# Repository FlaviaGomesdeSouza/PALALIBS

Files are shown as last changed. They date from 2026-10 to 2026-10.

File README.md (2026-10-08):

# Porta-amostras de 30 mm para pastilhas prensadas de 13 mm (LA-ICP-MS / LIBS)

É um cilindro com a seção de 30 mm que o porta-amostras do equipamento já aceita, com cavidades para
pastilhas de 13 mm. Segue a mesma ideia dos porta-amostras de seções polidas de MEV: a pastilha fica
**presa mecanicamente**, mesmo com o porta-amostras inclinado, e a **altura de cada pastilha é
ajustável**, de modo que todas as faces de análise ficam no mesmo plano. Não usa resina e não precisa
de polimento.

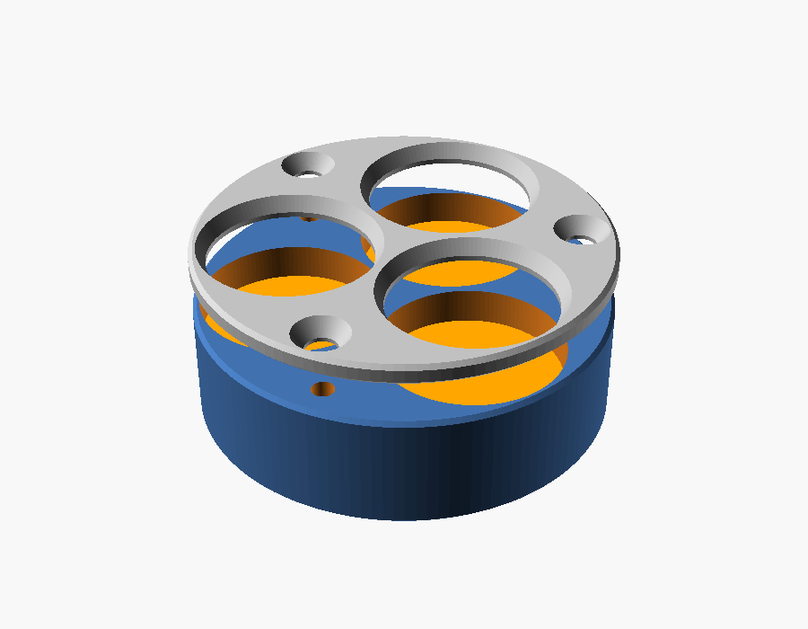
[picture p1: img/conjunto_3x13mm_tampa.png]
Conjunto para 3 pastilhas com tampa de fixação


## Ajuste de altura (todas as versões)

Cada cavidade tem um **pistão** (disco solto de 12,9 mm) sob a pastilha. Um **parafuso M3 sem cabeça**,
que entra por baixo, empurra o pistão para cima. Cada pastilha é regulada de forma independente, o que
compensa a diferença de espessura entre elas. O mesmo parafuso serve para extrair a pastilha.

## Fixação: duas opções

### A) Tampa de fixação (`fixacao = "tampa"`): recomendada; serve para 1, 2 ou 3 pastilhas

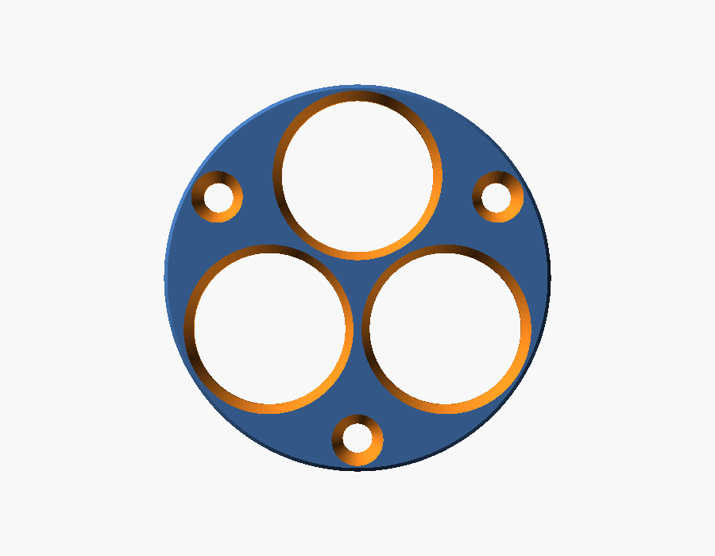
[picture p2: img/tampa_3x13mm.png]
Tampa


- A tampa é presa com parafusos M2 de cabeça chata escareada. Ela tem janelas de 11,8 mm, e a borda de
  cada janela cobre **0,6 mm** da borda da pastilha.
- Ao apertar o parafuso de baixo, a pastilha sobe até encostar na borda da janela. Isso **prende e
  nivela ao mesmo tempo**: todas as faces ficam encostadas no mesmo plano (a face inferior da tampa),
  seja qual for a espessura de cada pastilha.
- A face de análise fica 1,5 mm abaixo do topo. A janela tem chanfro, o que deixa espaço para o feixe e
  para o plasma com o porta-amostras inclinado.
- Área útil: círculo de ~11,8 mm em cada pastilha.

**Montagem:**
1. Coloque o pistão e a pastilha (face para cima) em cada cavidade.
2. Parafuse a tampa.
3. Por baixo, aperte cada parafuso M3 até a pastilha encostar na tampa. Encostou e travou, pare: o
   aperto deve ser leve, para não trincar a pastilha. Se quiser amortecer, coloque um disco fino de
   silicone ou de papel entre o pistão e a pastilha.

### B) Parafuso lateral com calço (`fixacao = "lateral"`): só para 1 ou 2 pastilhas

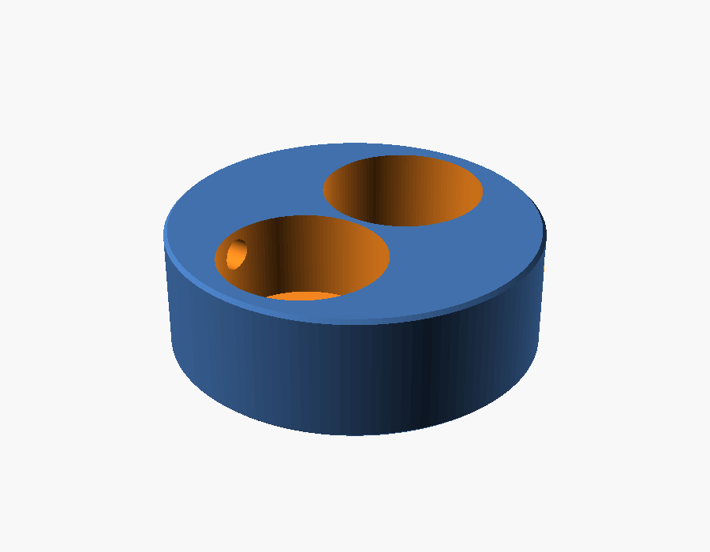
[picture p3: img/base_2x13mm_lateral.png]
Base com parafuso lateral


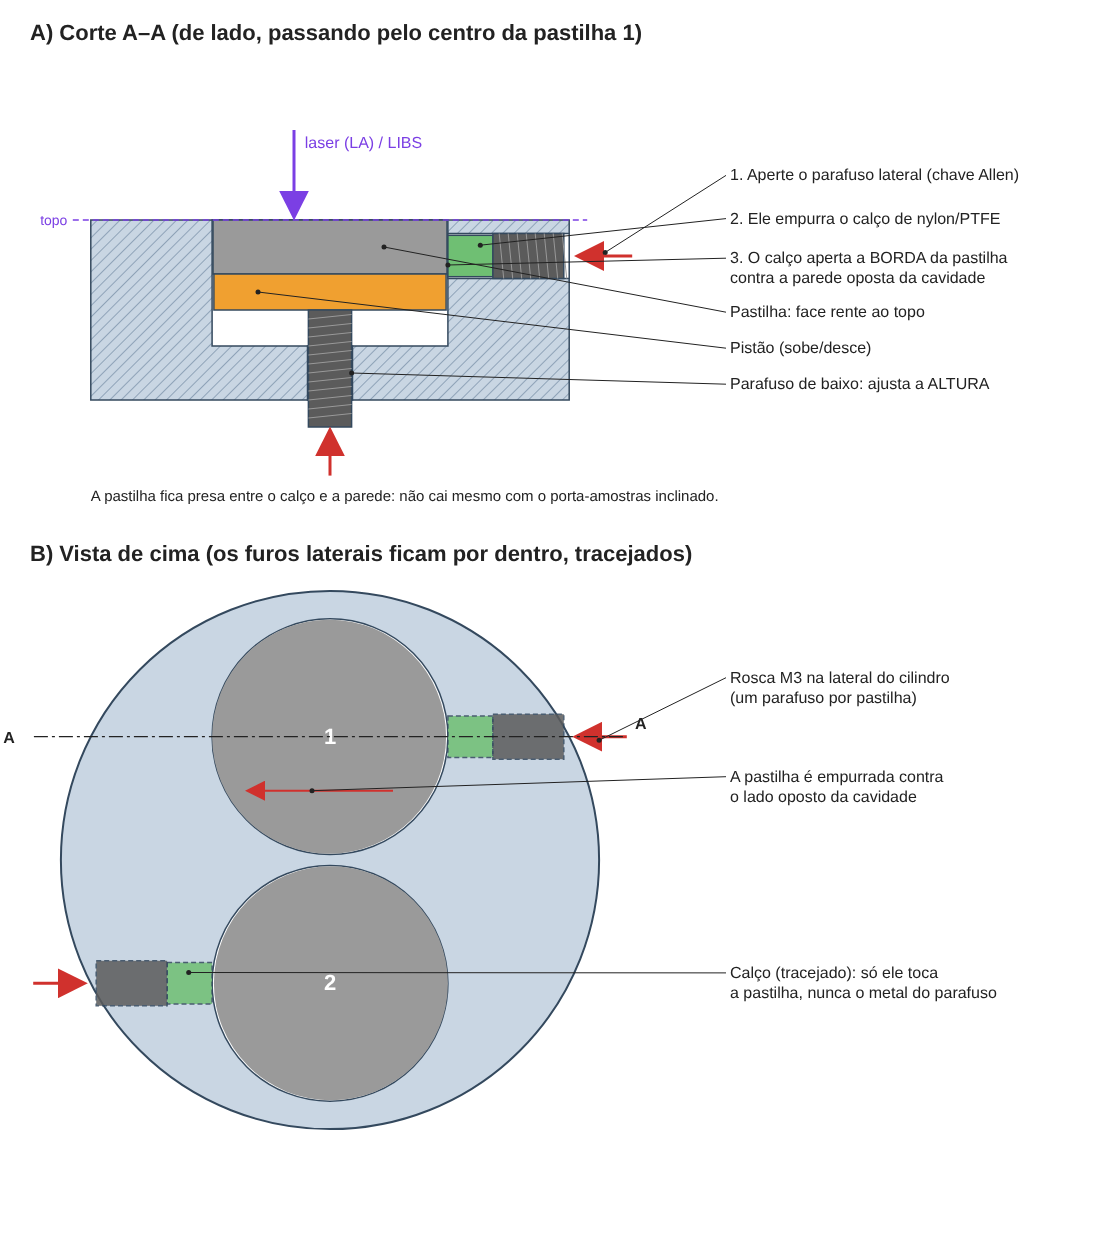
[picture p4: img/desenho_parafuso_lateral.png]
Como funciona o parafuso lateral: corte e vista de cima


- Um parafuso M3 sem cabeça entra pela lateral do cilindro, como nos porta-amostras de MEV, e empurra um
  **calço de nylon ou PTFE** (Ø 2,3 × 2,5 mm) contra a borda da pastilha.
- A face fica **rente ao topo**, e nenhuma parte da pastilha fica coberta.
- O furo lateral está a 2 mm abaixo do topo, então a pastilha precisa ter **pelo menos ~2 mm de
  espessura** para o calço alcançá-la. Para pastilhas mais finas, use a versão com tampa.
- **Com 3 pastilhas não é possível:** três círculos de 13 mm ocupam quase todo o círculo de 30 mm e a
  parede da borda fica com ~0,5 mm, sem espaço para rosca.

**Montagem e nivelamento:**
1. Apoie uma lâmina de vidro limpa na bancada e coloque as pastilhas sobre ela com a face de análise
   para baixo.
2. Encaixe a base por cima, de cabeça para baixo.
3. Coloque os pistões e aperte os parafusos de baixo só até encostar.
4. Aperte os parafusos laterais.
5. Vire o conjunto. As faces ficam rentes ao topo e no mesmo plano.

## Arquivos

| Arquivo | Peça |
|---|---|
| `porta_amostras_30mm.scad` | Modelo paramétrico (OpenSCAD). Abra em *Window → Customizer* para mudar as medidas. |
| `stl/base_3x13mm_tampa.stl` + `stl/tampa_3x13mm.stl` | 3 pastilhas, fixação por tampa (3 parafusos M2) |
| `stl/base_2x13mm_tampa.stl` + `stl/tampa_2x13mm.stl` | 2 pastilhas, fixação por tampa (2 parafusos M2) |
| `stl/base_2x13mm_lateral.stl` | 2 pastilhas, parafuso lateral |
| `stl/base_1x13mm_lateral.stl` | 1 pastilha, parafuso lateral |
| `stl/pistao_13mm.stl` | Pistão (um por cavidade) |
| `stl/calco_lateral.stl` | Calço do parafuso lateral; de preferência, corte de um tarugo de nylon ou PTFE |

### Parafusos (por suporte)

| Versão | Fundo (altura) | Fixação |
|---|---|---|
| Tampa, 3 pastilhas | 3 × M3 sem cabeça (DIN 913), 8–10 mm | 3 × M2 × 8 cabeça chata (DIN 965) |
| Tampa, 2 pastilhas | 2 × M3 sem cabeça, 8–10 mm | 2 × M2 × 8 cabeça chata |
| Lateral, 2 pastilhas | 2 × M3 sem cabeça, 8–10 mm | 2 × M3 sem cabeça, 6 mm, + 2 calços |

### Medidas padrão

- Ø externo 29,9 mm e altura total de 10 mm (com tampa: base de 8,5 mm + tampa de 1,5 mm).
- Cavidades de Ø 13,1 mm.
- Espessura máxima de pastilha: 3,5 mm na versão com tampa e 5 mm na versão lateral.

**Antes de fabricar, confira** a altura máxima que o porta-amostras do equipamento aceita e altere
`altura`, se precisar.

## Versão para impressão FDM (Bambu Lab X1 Carbon)

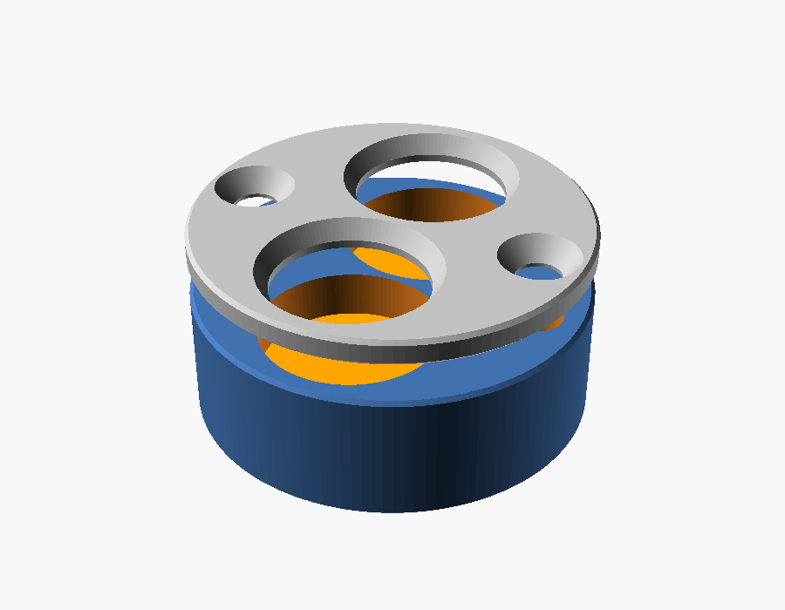
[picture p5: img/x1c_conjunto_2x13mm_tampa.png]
Versão X1C, 2 pastilhas com tampa


O arquivo `x1c_fdm.scad` usa o modelo principal com medidas próprias para FDM. Os STL prontos estão em
`stl/x1c/`.

**Diferenças em relação à versão usinada:**
- Configurada para **policarbonato (PC)**. Em `x1c_fdm.scad`, `material = "PETG"` troca as folgas para
  PETG.
- Folgas que compensam a contração do PC (~0,5–0,7 %): cavidade com +0,4 mm, seção com −0,1 mm e furo
  de inserto de 4,1 mm.
- Chanfro de 0,6 mm na borda de baixo, para absorver o "pé de elefante" da primeira camada.
- Todas as roscas são M3 em **insertos de latão**.
- Tampa de 2 mm presa com M3 escareado.
- Altura total de **12 mm**. Confira se o porta-amostras aceita essa altura; se não aceitar, altere
  `altura` em `x1c_fdm.scad`.
- Só 1 ou 2 pastilhas. A versão para 3 não é imprimível em FDM.

| Arquivo (`stl/x1c/`) | Peça |
|---|---|
| `teste_encaixe.stl` | Anel de 3 mm para testar a pastilha e o porta-amostras. **Imprima este primeiro.** |
| `base_2x13mm_tampa.stl` + `tampa_2x13mm.stl` | 2 pastilhas, com tampa (pastilhas de até 4,4 mm) |
| `base_1x13mm_tampa.stl` + `tampa_1x13mm.stl` | 1 pastilha, com tampa |
| `base_2x13mm_lateral.stl` / `base_1x13mm_lateral.stl` | Parafuso lateral (pastilhas de 2 a 6,4 mm) |
| `pistao_13mm.stl` | Pistão (um por cavidade) |

### Material

| Peça | Filamento | Por quê |
|---|---|---|
| Base, pistões e tampa | **PC transparente / natural** (sem pigmento) | É rígido, aguenta calor, cede pouco sob o aperto da tampa e não tem pigmento metálico. |

**PLA-CF não é recomendado para a tampa:**
- O PLA amolece a ~55–60 °C e **deforma com o tempo sob carga constante**: a pastilha afrouxa.
- A fibra deixa o PLA mais rígido, mas também **mais quebradiço**, e a borda da janela é fina.
- É sempre preto (fibra de carbono e negro de fumo). Se o laser pegar a borda, aparecem C e CN no LIBS.

Se quiser mesmo um filamento com fibra, use **PETG-CF** ou **PA-CF**, que deformam bem menos. O PA
precisa estar muito seco: absorve umidade, que depois sai na purga de He/Ar.

### Configuração de impressão em PC (Bambu Studio)
- **Secar o filamento:** o PC absorve umidade, e filamento úmido sai com bolhas e fios. Seque a 70–80 °C
  por 6–8 h em secadora e imprima direto da caixa seca (AMS com dessecante).
- **Perfil:** "Bambu PC" ou "Generic PC". Bico a 260–280 °C, mesa a 100–110 °C, ventilador entre 10 e
  30 %.
- **Câmara:** porta e tampa da X1C **fechadas**. Pré-aqueça a mesa por ~10 min antes de começar, para a
  câmara esquentar; isso reduz empenamento e trincas entre camadas.
- **Placa:** Engineering Plate ou Textured PEI, **com cola bastão** (o PC gruda forte demais no PEI liso
  e pode arrancar a superfície).
- **Camadas e preenchimento:** camadas de 0,12–0,16 mm, **preenchimento de 100 %** e 4 ou mais paredes.
- **Orientação:** base com o fundo na mesa e **ironing** no topo. Tampa com a **face inferior na mesa**,
  porque é a face que encosta nas pastilhas.
- **Brim:** de 3–5 mm na tampa, que é fina e plana. Na base, use se a borda levantar.
- **Retirada:** espere a placa esfriar antes de tirar as peças, para a tampa não entortar.
- **Contração:** **não** ligue a compensação de contração do fatiador; ela já está nas folgas do modelo.
- **Ordem:** imprima primeiro `teste_encaixe.stl`. Se a pastilha ficar justa demais, aumente
  `folga_pastilha` em 0,05–0,1; se a peça ficar folgada no porta-amostras, diminua `folga_secao`.

### Lista de compras (por suporte de 2 pastilhas, com tampa)

| Qtde | Item |
|---|---|
| 4 | Inserto de latão M3 para fixar a quente (M3 × 4 mm × Ø 4,5–5 mm; furo de 4,1 mm no modelo em PC) |
| 2 | Parafuso sem cabeça M3 × 10 mm, inox (DIN 913): ajuste de altura |
| 2 | Parafuso M3 × 10 mm escareado, inox (DIN 965 / ISO 10642): tampa |
| 1 | Chave Allen de 1,5 mm (+ chave Allen de 2 mm ou Phillips para a tampa, conforme o parafuso) |

Para a versão lateral, troque os 2 parafusos da tampa por **2 parafusos sem cabeça M3 × 6 mm com ponta
de nylon** e abra a rosca do furo lateral com **macho M3**. Para os insertos, use um ferro de solda
(~220 °C para PETG, ~260–280 °C para PC).

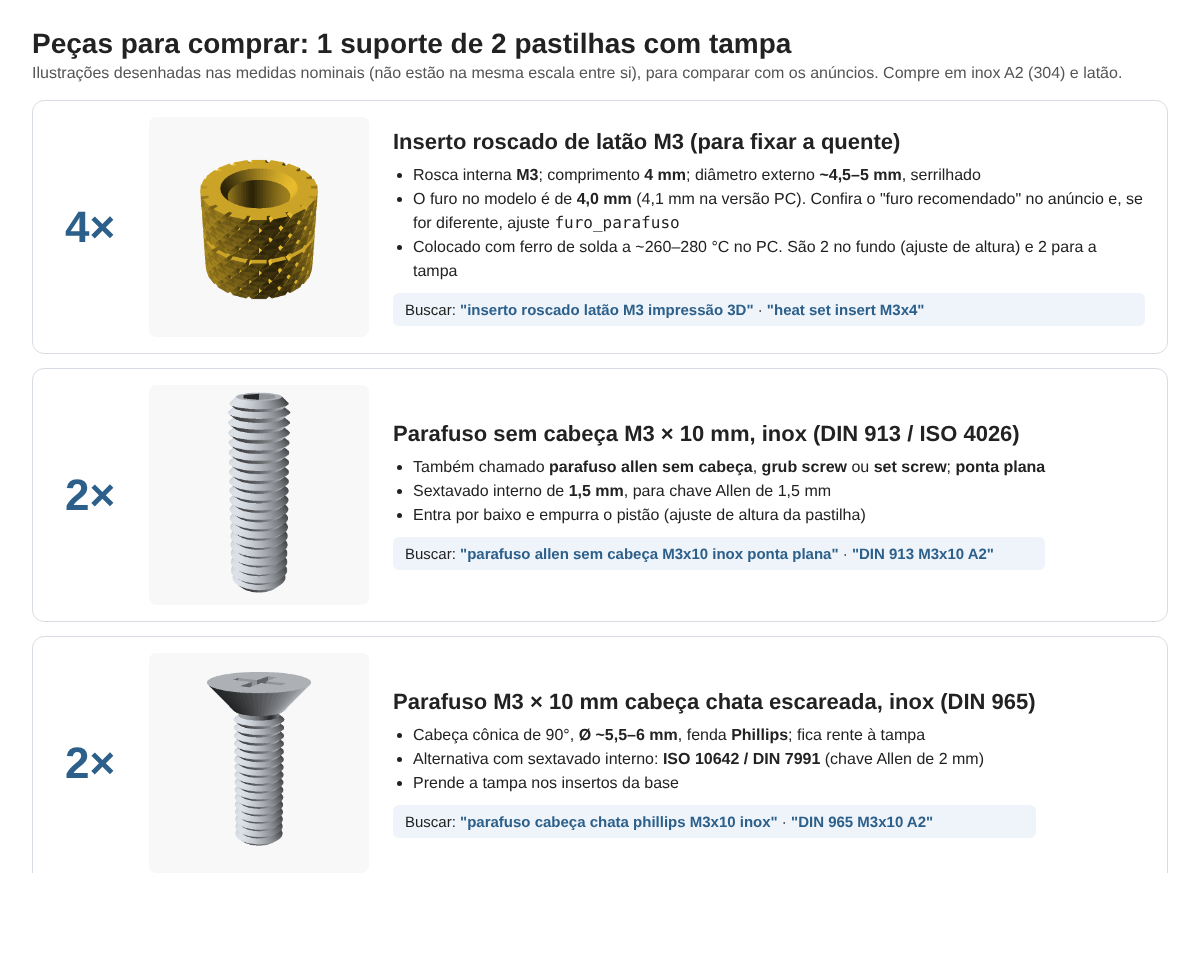
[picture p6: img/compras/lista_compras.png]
Peças para comprar


## Segundo modelo: ajuste de altura por mola (2 pastilhas, X1C em PC)

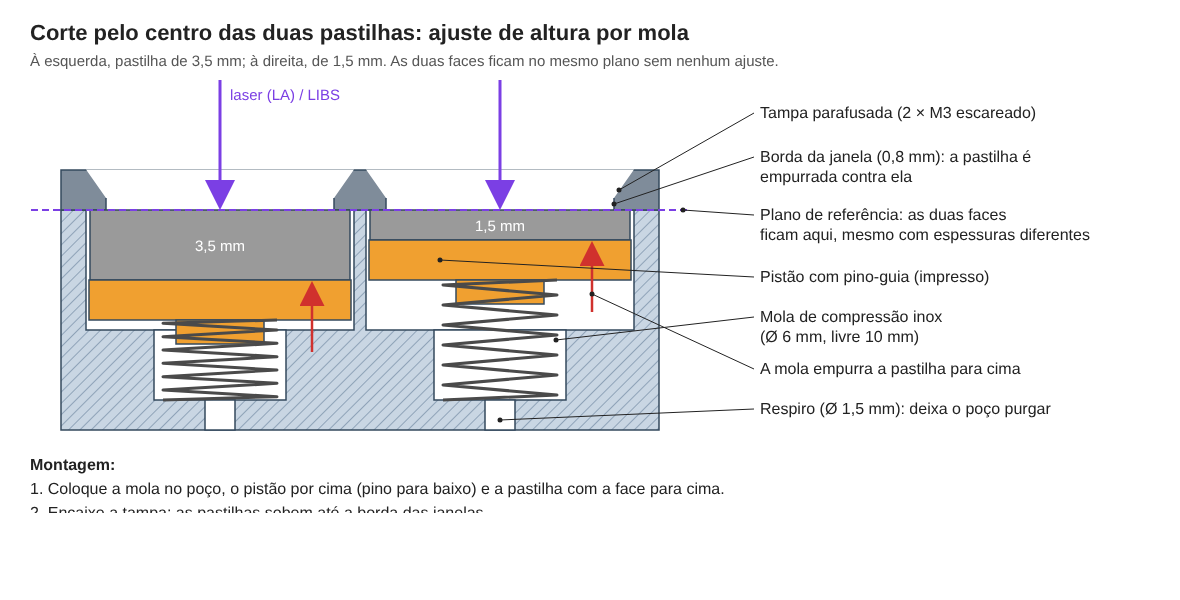
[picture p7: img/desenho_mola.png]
Corte do modelo com mola


Em `x1c_mola_2x13mm.scad`, a mola substitui o parafuso de ajuste. Cada pastilha apoia num pistão
empurrado por uma **mola de compressão**. Ao parafusar a tampa, as molas comprimem e mantêm cada pastilha
pressionada contra a borda da janela.

**Como funciona:**
- **Sem ajuste manual:** as duas faces ficam sempre no mesmo plano (a face inferior da tampa), para
  qualquer espessura entre **1 e 4 mm**, mesmo que cada pastilha tenha uma espessura diferente.
- **Pressão constante:** a força da mola não depende de quanto você aperta, então o risco de trincar a
  pastilha é menor.
- **Troca rápida:** ao soltar a tampa, a mola levanta a pastilha.
- **Respiro de Ø 1,5 mm** no fundo de cada poço, para o gás da célula de LA purgar o ar preso.
- **Altura total de 13 mm**, sendo a base de 11 mm e a tampa de 2 mm. Confira se o porta-amostras aceita
  essa altura.

| Arquivo (`stl/x1c_mola/`) | Peça |
|---|---|
| `base_2x13mm_mola.stl` | Base com 2 cavidades e 2 poços de mola |
| `tampa_2x13mm.stl` | Tampa (igual à da versão com parafuso) |
| `pistao_mola_13mm.stl` | Pistão com pino-guia (imprima 2, com a face plana na mesa) |

A configuração de impressão em PC é a mesma da seção anterior.

### Lista de compras (modelo com mola)

| Qtde | Item |
|---|---|
| 2 | **Mola de compressão inox**: Ø externo **6 mm**, comprimento livre **10 mm**, fio de **0,4–0,5 mm** (comprimento sólido ≤ 3 mm) |
| 2 | Inserto de latão M3 para fixar a quente (só para a tampa) |
| 2 | Parafuso M3 × 10 mm escareado, inox (DIN 965) |

Não precisa de parafuso sem cabeça. Buscar por *"mola de compressão inox 0,5 × 6 × 10 mm"* (fio × Ø
externo × comprimento) ou *"compression spring 0.5x6x10 stainless"*. Kits sortidos de molas pequenas
costumam ter essa medida. Com fio de 0,4 mm a força fica em ~1–2 N por pastilha; com fio de 0,5 mm, em
~3–5 N. As duas servem; prefira **0,4 mm** se as pastilhas forem frágeis (sem aglutinante).

## Quarto modelo (recomendado): carregado por baixo, mola leve e fundo de baioneta

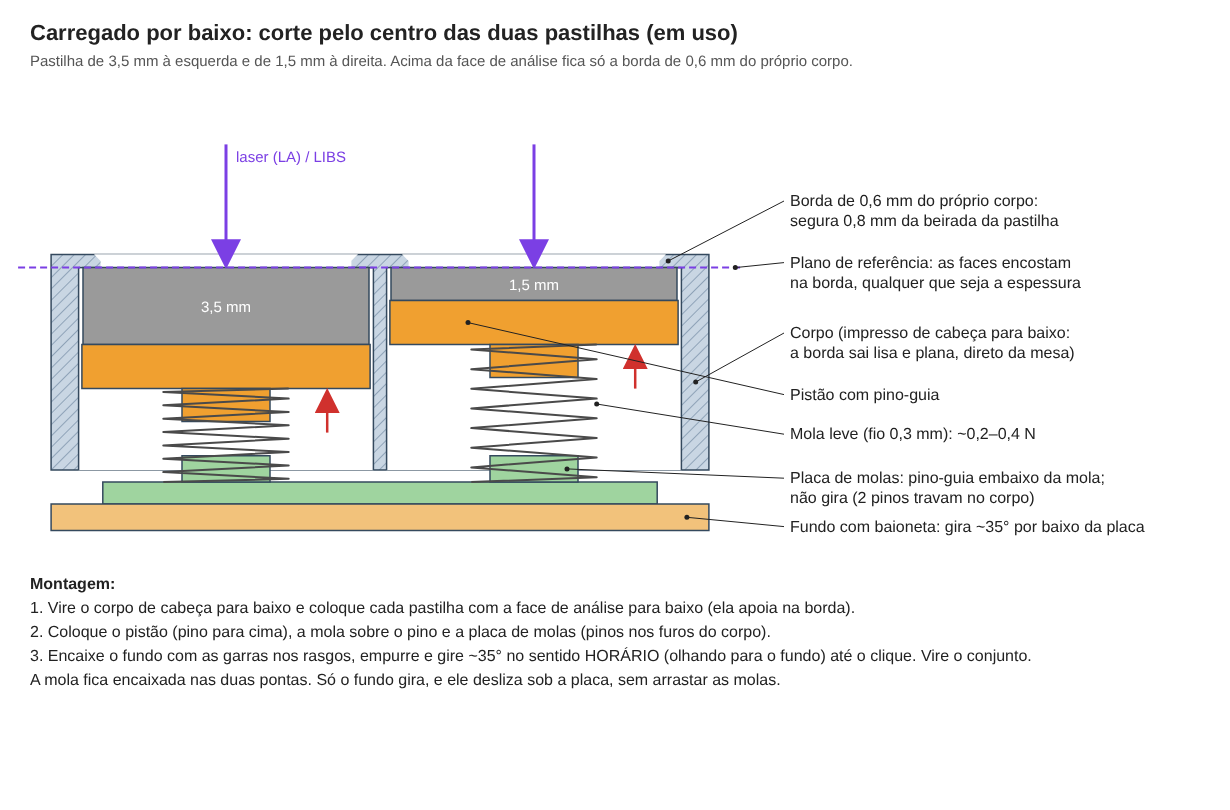
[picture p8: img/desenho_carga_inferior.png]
Corte do modelo carregado por baixo


Em `x1c_mola_carga_inferior_2x13mm.scad`, **não há tampa nem anel por cima**. A própria peça tem, no topo
de cada furo, uma **borda de 0,6 mm** que segura 0,8 mm da beirada da pastilha. A pastilha entra **por
baixo**, com a face de análise para baixo; a mola a empurra contra essa borda; e um **fundo de baioneta**
fecha tudo.

**Por que este modelo substitui tampa + anel finos:** uma tampa e um anel com menos de 1 mm de plástico,
presos só pelas 2 garras (no eixo x), flexionariam vários décimos de milímetro sob a mola, na região das
pastilhas (no eixo y). As faces sairiam inclinadas e fora do mesmo plano. Aqui:
- Acima da face de análise fica **só a borda de 0,6 mm**. Não há aro, tampa nem parafuso no topo.
- A borda é parte do corpo e está presa em toda a volta da janela, então praticamente não flexiona.
- O corpo é impresso **de cabeça para baixo**, então as duas bordas saem direto da mesa: planas e no
  mesmo plano.
- **Nada gira sobre a face da pastilha.** Só o fundo gira, e ele desliza por baixo da placa de molas.
- **A mola fica encaixada nas duas pontas:** em cima, no pino do pistão; embaixo, no pino da **placa de
  molas**. A placa não gira (2 pinos entram em furos no corpo), então o giro do fundo não arrasta as
  molas.
- Altura total de **12 mm** (12,55 mm com o fundo travado): corpo de 9,8 mm + placa de 1,0 mm + fundo de
  1,2 mm.

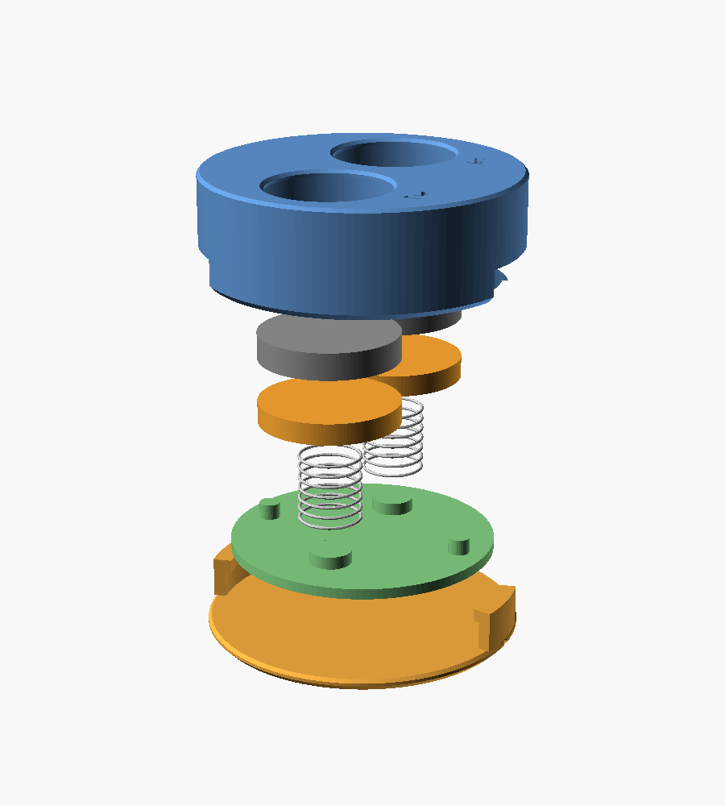
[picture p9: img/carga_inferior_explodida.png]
Vista explodida


**Montagem:**
1. Vire o corpo de cabeça para baixo e coloque cada pastilha **com a face de análise para baixo**. Ela
   apoia na borda.
2. Coloque o pistão (pino para cima) e a mola sobre o pino.
3. Coloque a placa de molas com os pinos para baixo: os 2 pinos-guia entram nas molas e os 2 pinos de
   trava entram nos furos do corpo.
4. Encaixe o fundo com as garras nos rasgos, **empurre e gire ~35° no sentido horário** (olhando para o
   fundo, com o corpo de cabeça para baixo) até o clique.
5. Vire o conjunto. Para abrir, empurre o fundo e gire no sentido contrário.

Os números 1 e 2 estão gravados no topo, ao lado de cada janela.

| Arquivo (`stl/x1c_carga_inferior/`) | Orientação (já exportado assim) |
|---|---|
| `corpo.stl` | **Topo na mesa** (de cabeça para baixo): as bordas saem planas da placa. |
| `placa.stl` | Face lisa na mesa, pinos para cima. |
| `fundo.stl` | Face de baixo na mesa, garras para cima. O dente da garra tem só 0,6 mm de saliência; não precisa de suporte. |
| `pistao.stl` | 2 unidades, face plana na mesa, pino para cima. |

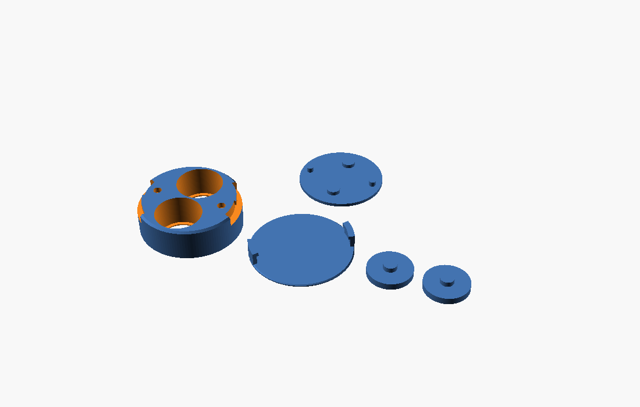
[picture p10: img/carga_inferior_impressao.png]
Peças na orientação de impressão


**Mola (compra):** 2 molas de compressão inox **leves**: Ø externo 6 mm, comprimento livre 10 mm, **fio de
0,3 mm** (comprimento sólido ≤ 3 mm). A força fica em ~0,2–0,4 N por pastilha. É muitas vezes o peso da
pastilha, suficiente para segurá-la com o porta-amostras inclinado, e não força a borda. Buscar por
*"mola de compressão inox 0,3 × 6 × 10 mm"*.

**Conferência:** a sobreposição entre corpo, placa de molas e fundo foi verificada no modelo na entrada,
no meio do giro, travado e travado apertado; só há contato de face, sem sobreposição. A borda de 0,6 mm e as folgas da
baioneta (`folga_b = 0,25`) são os pontos a confirmar na primeira impressão.

## Terceiro modelo: mola + tampa de baioneta (tudo impresso)

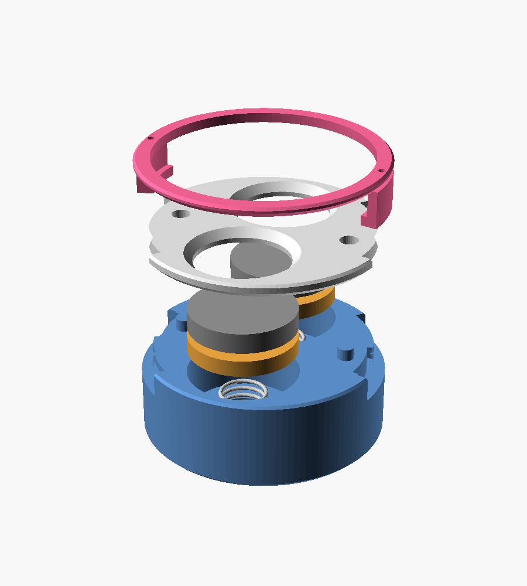
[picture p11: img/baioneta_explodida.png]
Vista explodida: base, molas, pistões, pastilhas, tampa e anel de baioneta


Em `x1c_mola_baioneta_2x13mm.scad`, o porta-amostras não tem rosca, parafuso nem inserto. **Só as 2 molas
são compradas.** O fechamento segue o princípio do pote de conserva:

- **Tampa:** disco plano com as janelas. Desce reto sobre as pastilhas e **não gira**, porque 2 pinos da
  base a travam. Assim nada raspa a face de análise.
- **Anel de baioneta:** aro fino por cima da tampa, com 2 garras. É a **única peça que gira**.
- **Trava:** a mola empurra a tampa e o anel para cima, e o dente de cada garra sobe num rebaixo. Isso dá
  o "clique" e impede que o anel gire sozinho.

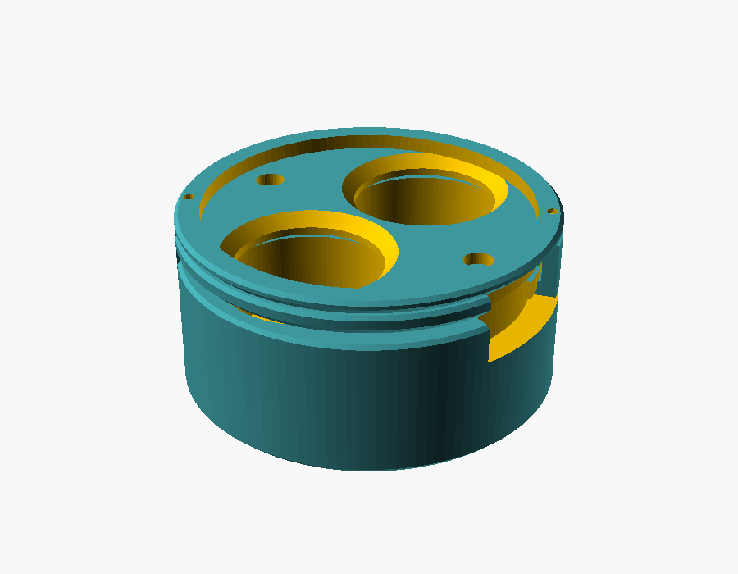
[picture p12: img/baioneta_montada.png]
Montado


**Montagem:**
1. Coloque a mola no poço, o pistão por cima (pino para baixo) e a pastilha com a face para cima.
2. Encaixe a tampa nos 2 pinos da base. Ela só entra numa posição e desce reta.
3. Posicione o anel com as garras nos rasgos da base. Os pontos gravados no aro ficam sobre as garras.
4. **Empurre para baixo e gire ~35° no sentido anti-horário** (visto de cima) até sentir o clique.
5. Para abrir, empurre e gire no sentido horário. A mola levanta a tampa e as pastilhas.

**Medidas:**
- Altura total de **14 mm**: base de 11,2 mm + tampa de 1,6 mm + aro de 1,2 mm. Confira se o
  porta-amostras aceita essa altura.
- Ao travar, a tampa fica 0,75 mm acima da base. As duas faces continuam no mesmo plano, encostadas na
  tampa.
- O aro do anel tem raio interno de 13 mm e não cobre a área útil das janelas.

| Arquivo (`stl/x1c_mola_baioneta/`) | Como imprimir |
|---|---|
| `base.stl` | Em pé (fundo na mesa), sem suporte. |
| `tampa.stl` | Face de baixo na mesa: é a face de referência que encosta nas pastilhas. |
| `anel.stl` | Já exportado **de cabeça para baixo** (aro na mesa, garras para cima), sem suporte. |
| `pistao.stl` | 2 unidades, face plana na mesa (pino para cima). |

Material e configuração: os mesmos da seção X1C (PC ou PETG; `material` no arquivo).

**Compra:** só **2 molas de compressão inox** (Ø 6 mm, livre 10 mm, fio 0,4–0,5 mm).

**Conferência do encaixe:** a interferência entre as peças foi verificada no modelo em três posições
(entrada, meio do giro e travado), e não há sobreposição. As folgas da baioneta (0,25 mm) e a pequena
saliência de 0,8 mm do dente são pontos a confirmar na primeira impressão. Se o giro ficar duro, aumente
`folga_b`.

## Fabricação

- **Versão para 3 pastilhas:** a parede da borda fica com ~0,5 mm. Usine em alumínio, PEEK ou POM
  (Delrin), ou imprima em resina SLA. Não use impressão FDM.
- **Tampa:** fica melhor em metal fino, como alumínio ou inox de 1,5 mm cortado a laser ou usinado,
  depois escareado.
- **Versões para 2 ou 1 pastilha:** são mais robustas e podem ser impressas em FDM (PETG) para teste.
- **Furos:** os de 2,5 mm são para abrir rosca M3 com macho, e os de 1,6 mm na base, para rosca M2. Em
  peça impressa, prefira insertos metálicos (aumente o furo conforme o inserto).
- **Teste de encaixe:** faça antes com uma pastilha real. `folga_pastilha` = 0,05–0,15 mm para usinagem
  e 0,15–0,25 mm para impressão.

## Contaminação

Só a pastilha é ablada. O suporte, a tampa e o calço não entram no plasma, desde que o laser não seja
posicionado na borda da janela. Recomenda-se:

- limpar as peças em ultrassom (água ultrapura / etanol) entre usos;
- fazer pré-ablação (pulsos de limpeza) antes da aquisição.

## Regenerar os STL

```sh
openscad -o stl/base_3x13mm_tampa.stl   -D 'peca="base"'  -D n_pastilhas=3 porta_amostras_30mm.scad
openscad -o stl/tampa_3x13mm.stl        -D 'peca="tampa"' -D n_pastilhas=3 porta_amostras_30mm.scad
openscad -o stl/base_2x13mm_lateral.stl -D 'peca="base"'  -D n_pastilhas=2 -D 'fixacao="lateral"' porta_amostras_30mm.scad
openscad -o stl/pistao_13mm.stl         -D 'peca="pistao"' porta_amostras_30mm.scad
```

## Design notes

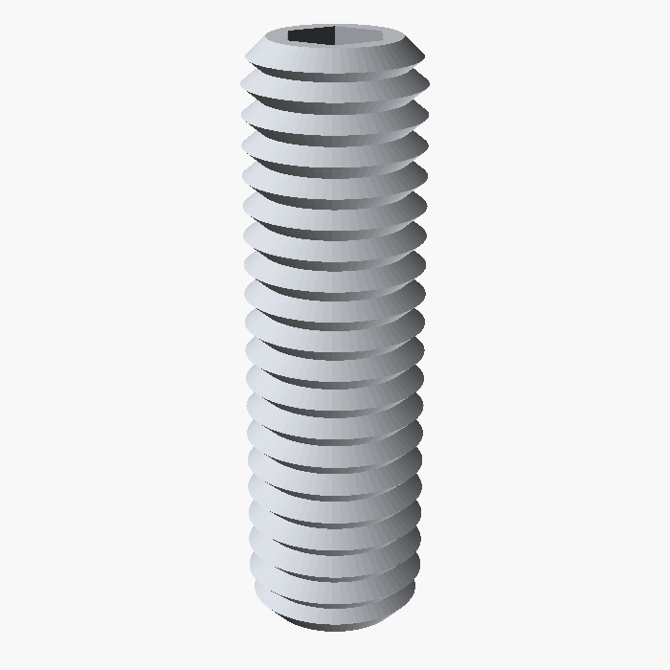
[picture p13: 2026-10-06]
img/compras/grub.png

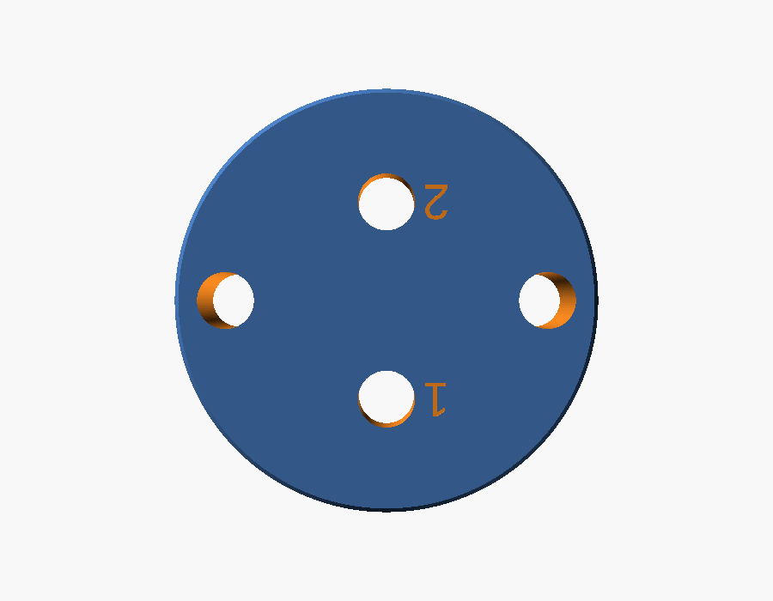
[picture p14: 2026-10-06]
img/x1c_fundo_2x13mm.png

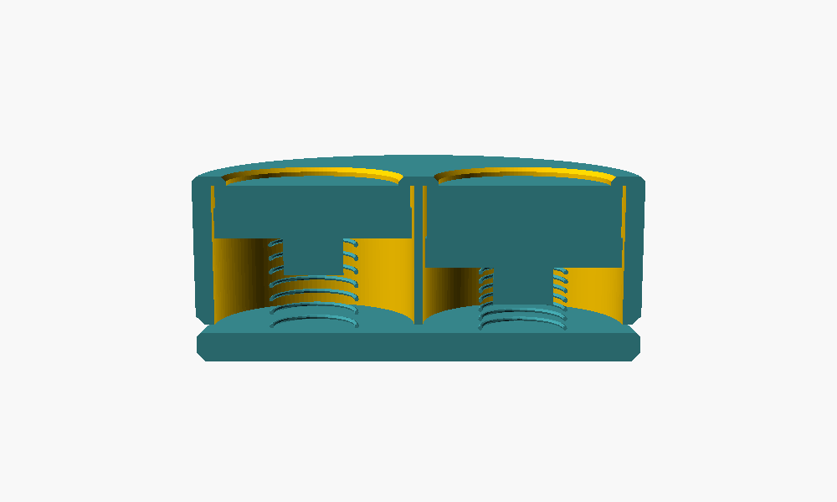
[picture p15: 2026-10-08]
img/carga_inferior_corte.png

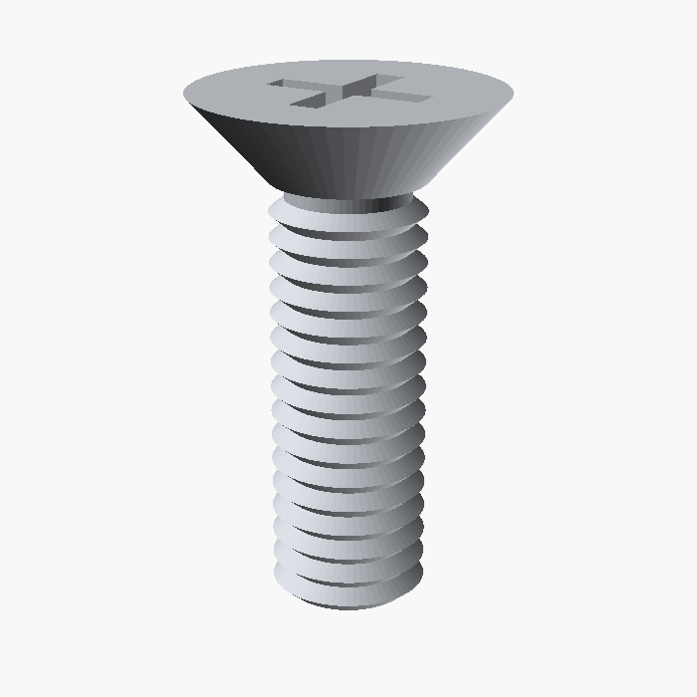
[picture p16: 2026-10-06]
img/compras/escareado.png

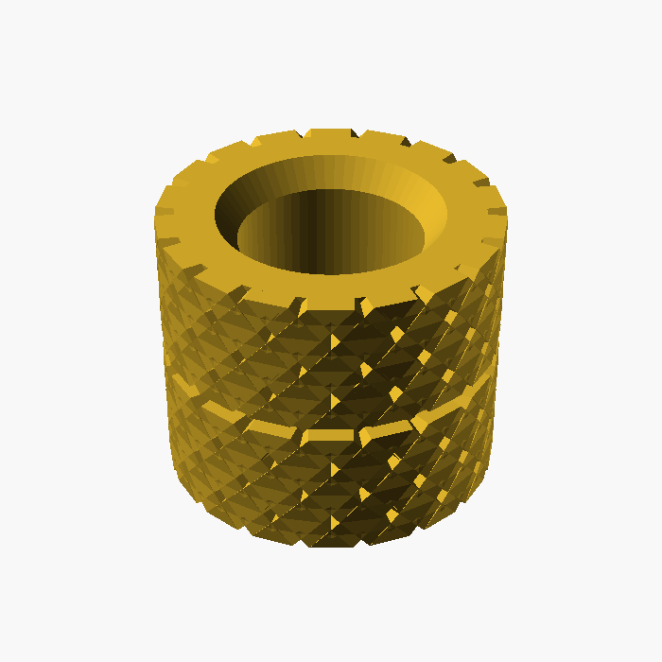
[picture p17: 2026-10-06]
img/compras/inserto.png

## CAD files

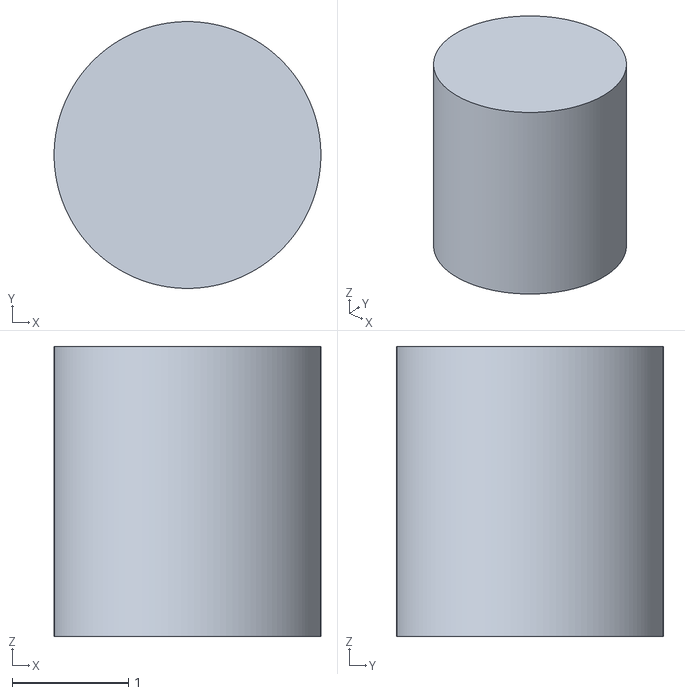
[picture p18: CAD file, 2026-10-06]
stl/calco_lateral.stl
2.30 x 2.30 x 2.50

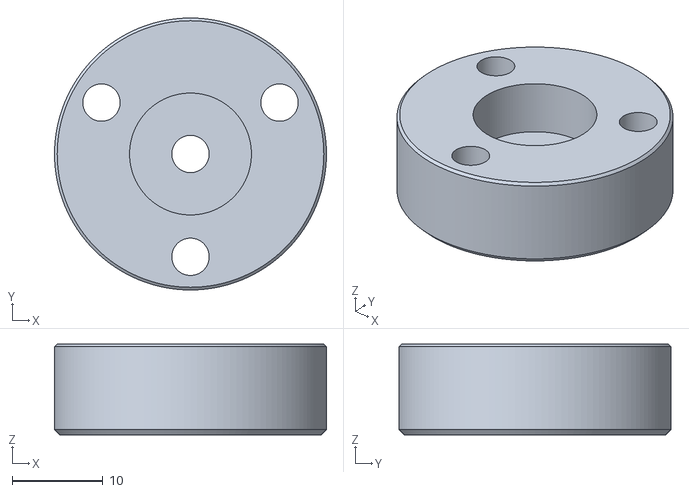
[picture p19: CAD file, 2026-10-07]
stl/x1c/base_1x13mm_tampa.stl
29.9 x 29.9 x 10.0

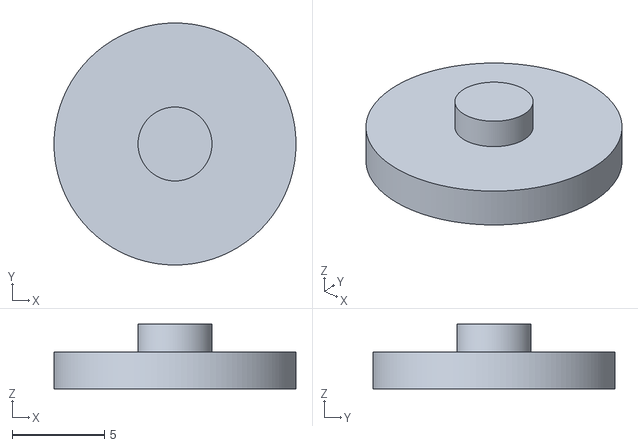
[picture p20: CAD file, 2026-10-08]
stl/x1c_carga_inferior/pistao.stl
13.1 x 13.1 x 3.50

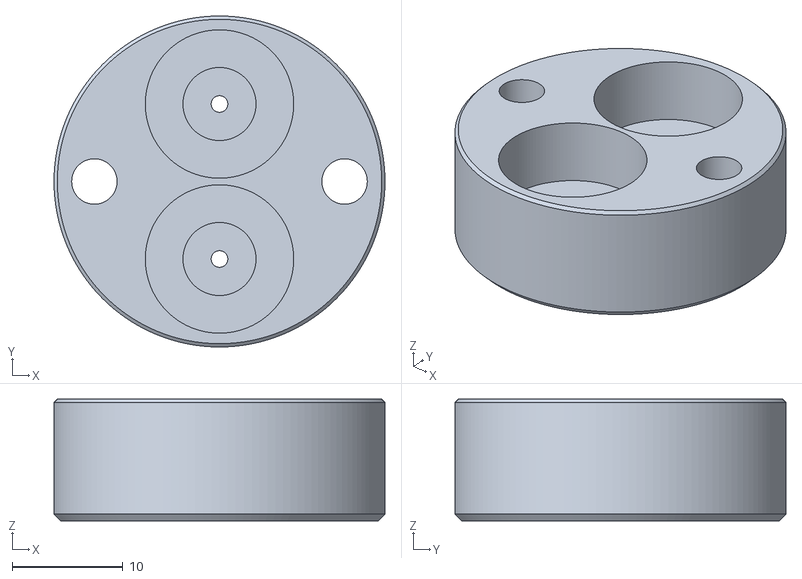
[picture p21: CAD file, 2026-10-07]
stl/x1c_mola/base_2x13mm_mola.stl
29.9 x 29.9 x 11.0

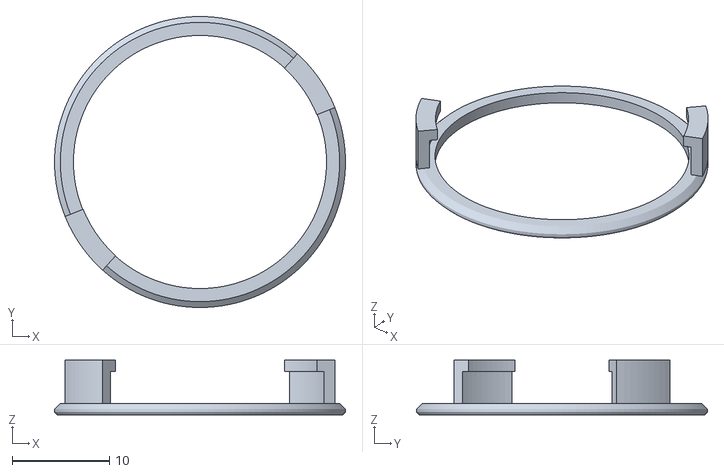
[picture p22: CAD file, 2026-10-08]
stl/x1c_mola_baioneta/anel.stl
29.9 x 29.9 x 5.65

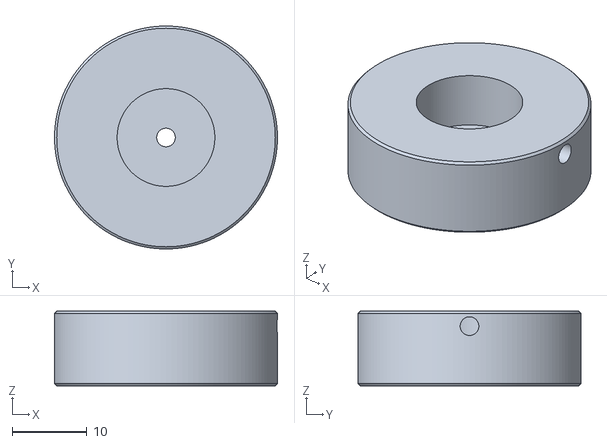
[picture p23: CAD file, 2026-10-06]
stl/base_1x13mm_lateral.stl
29.9 x 29.9 x 10.0

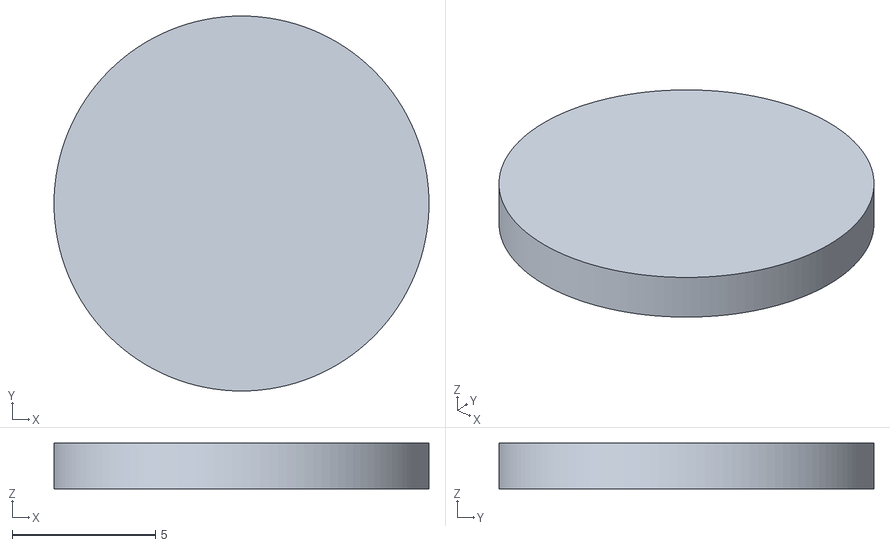
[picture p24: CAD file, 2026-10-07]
stl/x1c/pistao_13mm.stl
13.1 x 13.1 x 1.60

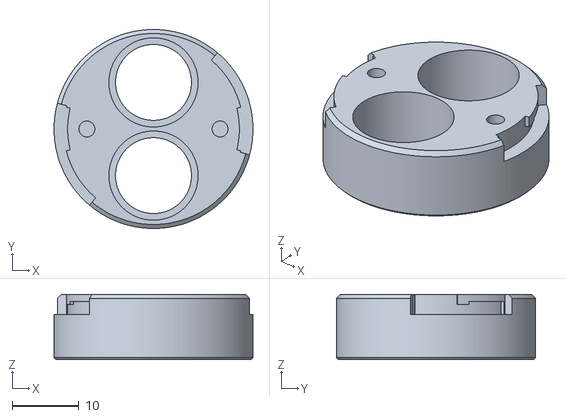
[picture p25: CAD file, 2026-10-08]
stl/x1c_carga_inferior/corpo.stl
29.9 x 29.9 x 9.80

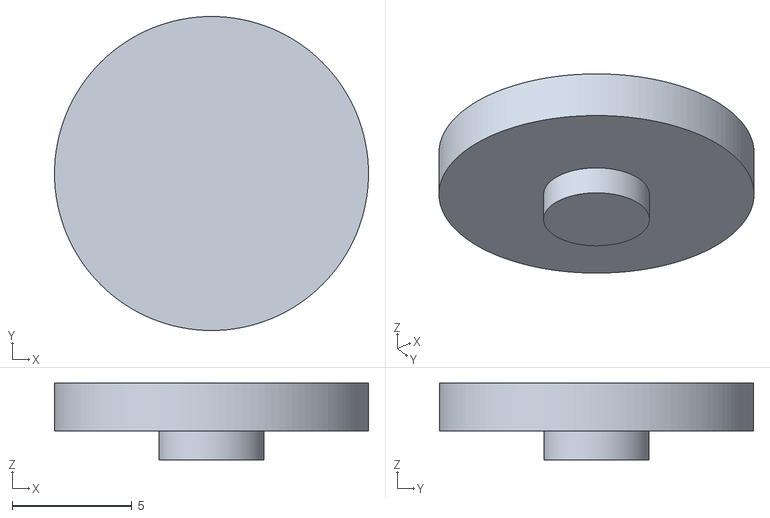
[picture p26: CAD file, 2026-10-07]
stl/x1c_mola/pistao_mola_13mm.stl
13.1 x 13.1 x 3.20

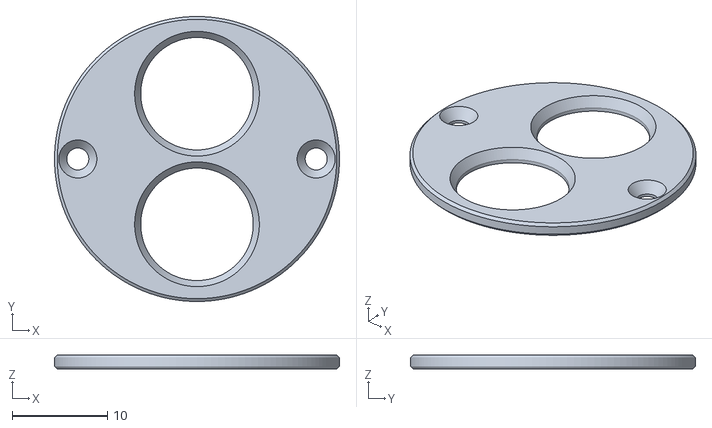
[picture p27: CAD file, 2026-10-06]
stl/tampa_2x13mm.stl
29.9 x 29.9 x 1.50

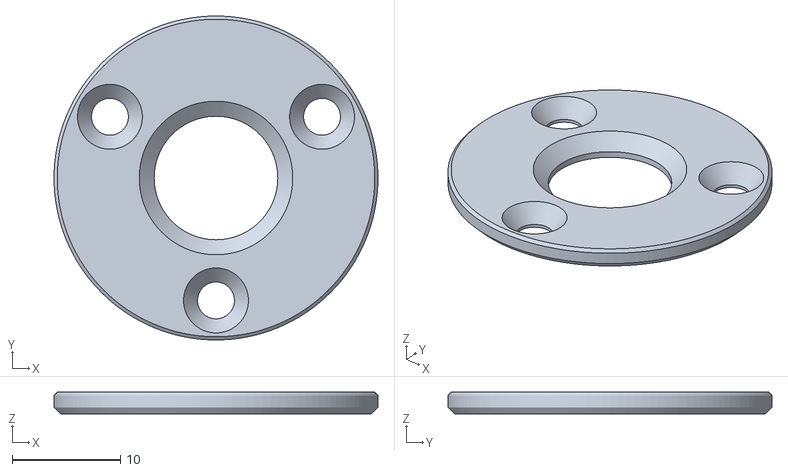
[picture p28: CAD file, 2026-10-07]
stl/x1c/tampa_1x13mm.stl
29.9 x 29.9 x 2.00

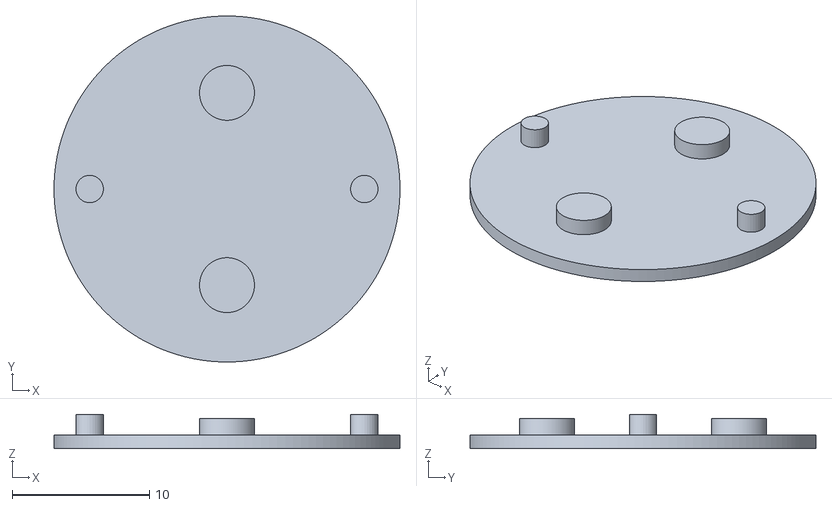
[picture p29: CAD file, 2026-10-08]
stl/x1c_carga_inferior/placa.stl
25.2 x 25.2 x 2.50

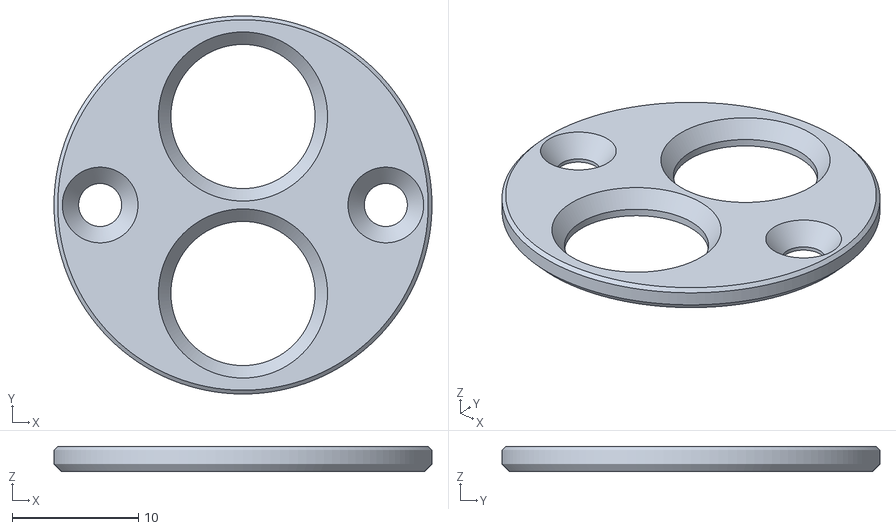
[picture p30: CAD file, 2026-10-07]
stl/x1c_mola/tampa_2x13mm.stl
29.9 x 29.9 x 2.00

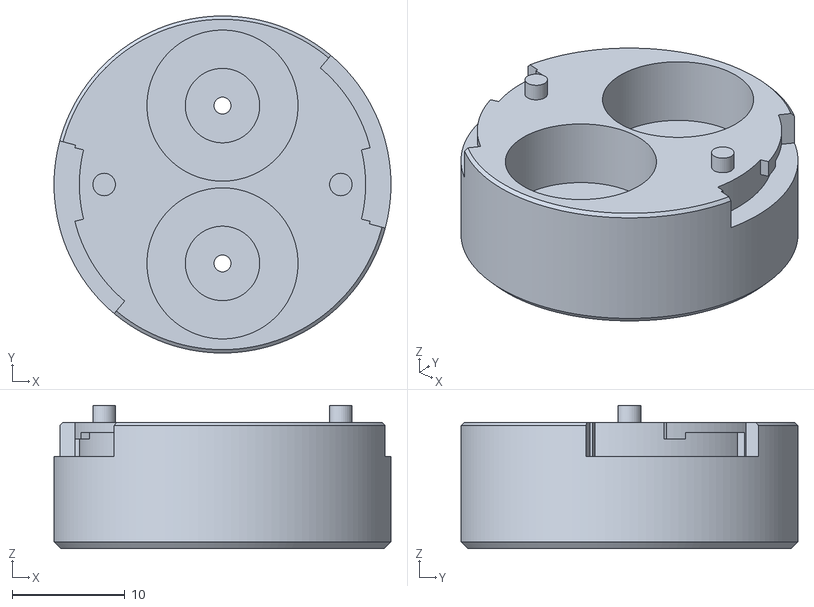
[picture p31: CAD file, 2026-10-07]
stl/x1c_mola_baioneta/base.stl
29.9 x 29.9 x 12.7

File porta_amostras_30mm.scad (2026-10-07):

// Porta-amostras com seção de 30 mm para pastilhas prensadas de 13 mm
// (LA-ICP-MS / LIBS), sem embutimento em resina e sem polimento.
// Mesma ideia dos porta-amostras de seções polidas de MEV: a pastilha
// fica presa mecanicamente e a altura de cada uma é ajustável.
//
// Cada cavidade tem um pistão (disco solto) sob a pastilha. O ajuste de
// altura (parâmetro "ajuste") é feito por:
//   "parafuso" – parafuso M3 por baixo que empurra o pistão (manual);
//   "mola"     – mola de compressão sob o pistão, que empurra a pastilha
//                contra a tampa (automático; exige fixacao = "tampa").
//
// Duas formas de prender a pastilha (parâmetro "fixacao"):
//   "tampa"   – tampa de topo com janelas um pouco menores que a pastilha.
//               O parafuso de baixo empurra a pastilha contra a borda da
//               janela: prende E nivela todas no mesmo plano, qualquer que
//               seja a espessura. Funciona com 1, 2 ou 3 pastilhas.
//   "lateral" – parafuso M3 radial pela lateral do cilindro, com um calço
//               de nylon/PTFE na ponta que aperta a borda da pastilha.
//               Só cabe com 1 ou 2 pastilhas (com 3 a parede tem ~0,5 mm).
//
// Peças: "base", "tampa", "pistao", "calco", "conjunto".

/* [Peça] */
peca = "conjunto"; // [base, tampa, pistao, calco, conjunto]
fixacao = "tampa"; // [tampa, lateral]
ajuste = "parafuso"; // [parafuso, mola]
// Material de impressão; só os presets (x1c_*.scad) usam. Precisa vir antes das folgas.
material = "";
// Modelos derivados que têm as próprias peças desligam a renderização deste arquivo
renderizar_principal = true;

/* [Seção do porta-amostras] */
// Diâmetro nominal da seção aceita pelo porta-amostras do equipamento (mm)
diametro_secao = 30;
// Folga diametral para entrar no porta-amostras (mm)
folga_secao = 0.1;
// Altura total do conjunto montado (mm); ajuste à altura que o equipamento aceita
altura = 10;

/* [Pastilhas] */
// Número de pastilhas (1, 2 ou 3)
n_pastilhas = 3; // [1, 2, 3]
// Diâmetro das pastilhas (mm)
diametro_pastilha = 13;
// Folga diametral da cavidade (mm); 0.05–0.15 para usinagem, 0.15–0.25 para impressão 3D
folga_pastilha = 0.1;
// Parede mínima entre cavidades vizinhas (mm)
parede_entre = 0.6;

/* [Ajuste de altura (fundo)] */
// Espessura do fundo, onde fica a rosca M3 (mm)
espessura_fundo = 3;
// Furo do fundo: 2.5 para abrir rosca M3 com macho; 3.2 para M3 com porca/inserto
furo_parafuso = 2.5;
// Espessura do pistão (mm)
espessura_pistao = 2;
// Folga diametral entre pistão e cavidade (mm)
folga_pistao = 0.2;

/* [Mola (ajuste = mola)] */
// Faixa de espessura de pastilha que a mola cobre (mm)
espessura_min_pastilha = 1;
espessura_max_pastilha = 4;
// Mola de compressão: diâmetro externo, comprimento livre e comprimento sólido (mm)
d_mola = 6;
comprimento_livre_mola = 10;
comprimento_solido_mola = 3;
// Folga diametral do poço da mola (mm)
folga_mola = 0.6;
// Pino-guia sob o pistão, que entra na mola e a mantém centrada (mm)
d_guia_pistao = 4.4;
h_guia_pistao = 1.2;
// Furo de respiro no fundo do poço (mm); 0 para fechar
furo_respiro = 1.5;

/* [Tampa (fixacao = tampa)] */
// Espessura da tampa (mm); a face da pastilha fica esse tanto abaixo do topo
espessura_tampa = 1.5;
// Quanto a borda da janela cobre a pastilha, no raio (mm)
aba = 0.6;
// Parte reta da borda da janela antes do chanfro (mm)
aba_reta = 0.4;
// Raio do círculo dos parafusos M2 da tampa (mm)
r_parafusos_tampa = 12.5;
// Furo na base para os parafusos da tampa: 1.6 para rosca M2 com macho
furo_tampa_base = 1.6;
// Furo passante na tampa e escareado da cabeça (M2 DIN 965: 2.3 / 4.0 / 1.2)
furo_tampa = 2.3;
d_cabeca_tampa = 4.0;
h_cabeca_tampa = 1.2;

/* [Parafuso lateral (fixacao = lateral)] */
// Furo lateral: 2.5 para abrir rosca M3 com macho
furo_lateral = 2.5;
// Profundidade do eixo do furo lateral abaixo do topo (mm); mínimo furo_lateral/2 + 0.5
z_lateral = 2.0;
// Diâmetro e comprimento do calço de nylon/PTFE
diametro_calco = 2.3;
comprimento_calco = 2.5;

/* [Acabamento] */
chanfro = 0.3;
// Chanfro da borda de baixo (compensa o "pé de elefante" da 1ª camada no FDM)
chanfro_inferior = 0.3;
$fn = 128;

d_secao = diametro_secao - folga_secao;
d_cavidade = diametro_pastilha + folga_pastilha;
d_pistao = d_cavidade - folga_pistao;
t_tampa = fixacao == "tampa" ? espessura_tampa : 0;
altura_base = altura - t_tampa;
mola = ajuste == "mola";
prof_cavidade = mola ? espessura_max_pastilha + espessura_pistao : altura_base - espessura_fundo;
z_fundo_cavidade = altura_base - prof_cavidade;
// Mola: comprimento comprimido com a pastilha mais grossa e com a mais fina
mola_min = z_fundo_cavidade - espessura_fundo;
mola_max = mola_min + espessura_max_pastilha - espessura_min_pastilha;
d_janela = diametro_pastilha - 2 * aba;
dist_centros = d_cavidade + parede_entre;

r_centros = n_pastilhas == 1 ? 0
          : n_pastilhas == 2 ? dist_centros / 2
          : dist_centros / sqrt(3);
parede_externa = d_secao / 2 - r_centros - d_cavidade / 2;

// Janela da tampa: chanfro de 45° para cima, limitado para não encostar na vizinha
d_janela_topo = min(d_janela + 2 * (espessura_tampa - aba_reta),
                    n_pastilhas > 1 ? dist_centros - 0.6 : d_secao,
                    2 * (d_secao / 2 - r_centros) - 0.6);

n_parafusos_tampa = n_pastilhas == 1 ? 3 : n_pastilhas;

echo(str("Parede externa mínima: ", parede_externa, " mm"));
echo(str("Espessura de pastilha aceita: ", mola ? str(espessura_min_pastilha, " a ") : "até ",
         prof_cavidade - espessura_pistao, " mm"));
if (mola)
    echo(str("Mola comprimida entre ", mola_min, " e ", mola_max, " mm (livre ",
             comprimento_livre_mola, ", sólida ", comprimento_solido_mola, ")"));
assert(!mola || fixacao == "tampa", "Ajuste por mola precisa da tampa (fixacao = \"tampa\")");
assert(!mola || mola_min >= comprimento_solido_mola + 0.3,
       "Poço curto: a mola chega ao comprimento sólido; aumente a altura ou reduza espessura_max_pastilha");
assert(!mola || mola_max <= comprimento_livre_mola - 1,
       "Mola sem pré-carga com a pastilha mais fina; use mola mais longa");
assert(!mola || h_guia_pistao < mola_min, "Pino-guia maior que o poço");
assert(parede_externa > 0.3, "Parede externa < 0,3 mm: reduza parede_entre ou n_pastilhas");
assert(fixacao == "lateral" || r_parafusos_tampa + d_cabeca_tampa / 2 < d_secao / 2 - 0.4,
       "Cabeça do parafuso da tampa sai da borda: reduza r_parafusos_tampa");
assert(prof_cavidade > espessura_pistao, "Cavidade rasa demais para o pistão");
if (fixacao == "lateral")
    echo(str("Calço lateral: pastilhas com pelo menos ~", z_lateral, " mm de espessura"));
assert(fixacao == "tampa" || z_lateral >= furo_lateral / 2 + 0.5, "Furo lateral rompe o topo: aumente z_lateral");
assert(fixacao == "tampa" || n_pastilhas <= 2,
       "Parafuso lateral não cabe com 3 pastilhas em 30 mm; use fixacao = \"tampa\"");

function angulo(i) = 90 + i * 360 / n_pastilhas;
function centros() = [for (i = [0 : n_pastilhas - 1])
    [r_centros * cos(angulo(i)), r_centros * sin(angulo(i))]];
function parafusos_tampa() = [for (i = [0 : n_parafusos_tampa - 1])
    let(a = 90 + 180 / n_parafusos_tampa + i * 360 / n_parafusos_tampa)
    [r_parafusos_tampa * cos(a), r_parafusos_tampa * sin(a)]];
// Parafuso lateral: sai da cavidade para fora, perpendicular à linha dos centros
function dir_lateral(i) = n_pastilhas == 1 ? 0 : angulo(i) - 90;

module cilindro_chanfrado(d, h) {
    hull() {
        translate([0, 0, chanfro_inferior]) cylinder(d = d, h = h - chanfro_inferior - chanfro);
        cylinder(d = d - 2 * chanfro_inferior, h = h - chanfro);
        translate([0, 0, chanfro]) cylinder(d = d - 2 * chanfro, h = h - chanfro);
    }
}
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

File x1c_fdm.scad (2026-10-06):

// Preset para impressão FDM (Bambu Lab X1 Carbon, bico 0,4 mm).
// Usa o modelo principal e só troca as medidas que mudam no FDM:
// folgas por material, insertos de latão M3 e tampa mais grossa.
// Em OpenSCAD a última atribuição vale, então estes valores substituem
// os do arquivo incluído.

include <porta_amostras_30mm.scad>

/* [Peça] */
peca = "conjunto"; // [base, tampa, pistao, conjunto]
fixacao = "tampa"; // [tampa, lateral]
// FDM: só 1 ou 2 pastilhas (com 3 a parede fica com ~0,5 mm)
n_pastilhas = 2; // [1, 2]
// PC contrai ~0,5–0,7 % ao esfriar: furos saem menores e o externo também
material = "PC"; // [PC, PETG]

// Altura total: confira o máximo que o porta-amostras do equipamento aceita
altura = 12;

// Folgas por material (ajuste depois do anel de teste).
// Não use ao mesmo tempo a compensação de contração do fatiador.
folga_secao    = material == "PC" ? 0.1  : 0.2;
folga_pastilha = material == "PC" ? 0.4  : 0.25;
folga_pistao   = 0.3;
furo_parafuso  = material == "PC" ? 4.1  : 4.0;   // inserto M3 no fundo
furo_tampa_base = furo_parafuso;                  // inserto M3 da tampa
chanfro_inferior = 0.6;

// Fundo com inserto de latão M3 para o parafuso de altura
espessura_fundo = 4;
espessura_pistao = 1.6;

// Tampa de 2 mm presa com M3 escareado (DIN 965) em insertos M3
espessura_tampa = 2.0;
aba = 0.8;
aba_reta = 0.6;
r_parafusos_tampa = 11.3;
furo_tampa = 3.4;
d_cabeca_tampa = 6.0;
h_cabeca_tampa = 1.7;

// Parafuso lateral M3 com ponta de nylon, rosca aberta com macho direto no plástico
furo_lateral = 2.5;
z_lateral = 2.0;

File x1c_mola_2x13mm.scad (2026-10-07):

// Segundo modelo: porta-amostras de 30 mm para 2 pastilhas de 13 mm com
// ajuste de altura por MOLA (Bambu Lab X1C, PC).
//
// Cada pastilha apoia num pistão empurrado por uma mola de compressão.
// Ao parafusar a tampa, as molas comprimem e mantêm cada pastilha
// pressionada contra a borda da janela: todas ficam no mesmo plano, sem
// nenhum ajuste manual, para qualquer espessura entre 1 e 4 mm.
//
// Usa o preset FDM (folgas de PC, insertos M3 da tampa) e troca o fundo
// com parafuso por poços de mola.

include <x1c_fdm.scad>

/* [Peça] */
peca = "conjunto"; // [base, tampa, pistao, conjunto]
fixacao = "tampa";
ajuste = "mola";
n_pastilhas = 2;
material = "PC"; // [PC, PETG]

// Altura total: confira o máximo que o porta-amostras do equipamento aceita
altura = 13;

// Faixa de espessura das pastilhas
espessura_min_pastilha = 1;
espessura_max_pastilha = 4;

// Fundo abaixo do poço da mola e pistão com pino-guia
espessura_fundo = 1.5;
espessura_pistao = 2;

// Mola de compressão inox: Ø externo 6 mm, livre 10 mm, sólida <= 3 mm (fio 0,4–0,5 mm)
d_mola = 6;
comprimento_livre_mola = 10;
comprimento_solido_mola = 3;

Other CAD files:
stl/x1c_mola_baioneta/pistao.stl
stl/base_3x13mm_tampa.stl
stl/x1c/base_1x13mm_lateral.stl
stl/x1c_carga_inferior/fundo.stl
x1c_mola_baioneta_2x13mm.scad
img/baioneta_explodida.scad
img/carga_inferior_vistas.scad
img/compras/pecas_compra.scad
stl/base_2x13mm_lateral.stl
stl/base_2x13mm_tampa.stl
stl/pistao_13mm.stl
stl/tampa_3x13mm.stl
stl/x1c/base_2x13mm_lateral.stl
stl/x1c/base_2x13mm_tampa.stl
stl/x1c/tampa_2x13mm.stl
stl/x1c/teste_encaixe.stl
stl/x1c_mola_baioneta/tampa.stl
x1c_mola_carga_inferior_2x13mm.scad

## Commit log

2026-10-06 Porta-amostras de 30 mm para pastilhas prensadas de 13 mm
    Modelo OpenSCAD paramétrico (1-3 cavidades, pistão e parafuso M3 de
    nivelamento), STLs prontos e README com fabricação e uso.
    Claude-Session: https://claude.ai/code/session_01F2pygBXkKwoHBZkjMgw7Yb
    [pistao_13mm.stl, porta_amostras_30mm.scad, suporte_1x13mm.stl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]
2026-10-06 Fixação das pastilhas para porta-amostras inclinado
    Adiciona tampa de fixação (prende e nivela as pastilhas contra a borda
    da janela; 1-3 pastilhas) e opção de parafuso lateral com calço de
    nylon/PTFE (1-2 pastilhas), mantendo o ajuste de altura por pistão.
    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
    [base_1x13mm_lateral.stl, base_2x13mm_lateral.stl, base_2x13mm_tampa.stl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]
2026-10-06 Preset para impressão FDM na Bambu Lab X1C
    x1c_fdm.scad: folgas de FDM, insertos de latão M3, tampa de 2 mm com M3
    escareado e anel de teste de encaixe. Parafusos da tampa parametrizados.
    README com material, configuração de impressão e lista de compras.
    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
    [base_1x13mm_lateral.stl, base_1x13mm_tampa.stl, base_2x13mm_lateral.stl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]
2026-10-06 X1C: preset para policarbonato e folha de compras ilustrada
    x1c_fdm.scad passa a ter material PC (padrão) ou PETG, com folgas que
    compensam a contração do PC e chanfro inferior contra pé de elefante.
    README com configuração de impressão em PC; ilustrações das peças
    compradas (inserto M3, DIN 913, DIN 965) com termos de busca.
    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
    [base_1x13mm_lateral.stl, base_1x13mm_tampa.stl, base_2x13mm_lateral.stl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]
2026-10-07 Modelo com ajuste de altura por mola (2 pastilhas, X1C/PC)
    Opção ajuste = "mola" no modelo: poço de mola sob cada cavidade, pistão
    com pino-guia e respiro. Preset x1c_mola_2x13mm.scad, STLs e desenho em
    corte. Corrige o preset X1C: 'material' era lido antes de ser definido,
    e os STL em PC saíam com as folgas de PETG.
    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
    [base_1x13mm_lateral.stl, base_1x13mm_tampa.stl, base_2x13mm_lateral.stl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]
2026-10-07 Terceiro modelo: mola + tampa de baioneta, tudo impresso
    Tampa plana travada por pinos (não gira sobre as pastilhas) e anel de
    baioneta com 2 garras, canal sob ressalto e rebaixo de trava. Sem rosca,
    parafuso ou inserto; só as 2 molas são compradas. Interferência entre
    peças verificada nas posições de entrada, meio do giro e travado.
    Arquivo principal ganha renderizar_principal para modelos derivados.
    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
    [anel.stl, baioneta_explodida.scad, base.stl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]
2026-10-08 Quarto modelo: carregado por baixo, borda de 0,6 mm e fundo de baioneta
    Sem tampa nem anel por cima: a borda de 0,6 mm do próprio corpo segura a
    pastilha, que entra por baixo e é empurrada por mola leve (fio 0,3 mm).
    Fundo com baioneta (só ele gira). Peças exportadas já na orientação de
    impressão; anel do modelo anterior também passa a sair com o aro na mesa.
    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
    [anel.stl, carga_inferior_vistas.scad, corpo.stl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]
2026-10-08 Placa de molas no modelo carregado por baixo
    Encaixe da mola também embaixo: placa com pinos-guia, travada no corpo
    por 2 pinos para não girar; o fundo de baioneta gira por baixo dela sem
    arrastar as molas. Fundo passa a 1,2 mm e corpo a 9,8 mm (altura total
    mantida em 12 mm). Interferências verificadas em todas as posições.
    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
    [carga_inferior_vistas.scad, corpo.stl, fundo.stl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]
